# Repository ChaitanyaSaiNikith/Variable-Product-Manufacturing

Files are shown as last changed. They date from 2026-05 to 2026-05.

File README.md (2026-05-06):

# ME500 Variable Product Manufacturing — Thursday PM Lab Group

**Course:** ME500: Advanced Manufacturing — Spring 2026  
**Team:** Chris Daub, Riley Hubscher, Mukhamed Kerimkul, Bramasto Prasojo, and Chaitanya Sai Nikith Rambha  

---

## Project Overview

This project implements a **Variable Product Manufacturing (VPM)** system in the ADML. The system autonomously produces two variants of a swivel hook product — **Short Hook (Product A)** and **Tall Hook (Product B)** — each consisting of a CNC-machined lid, a CNC-machined base, and a 3D-printed hook. A computer vision system identifies the lid type and directs the correct assembly procedure.

The system integrates three UR5 robots (Rosie, Mary, Edie), two Haas Mini Mills (Cayenne, Paprika), a conveyor belt, an Allen-Bradley SLC500 PLC, and a top-down webcam — all orchestrated by BUMES (Boston University Manufacturing Execution System).

---

## Products

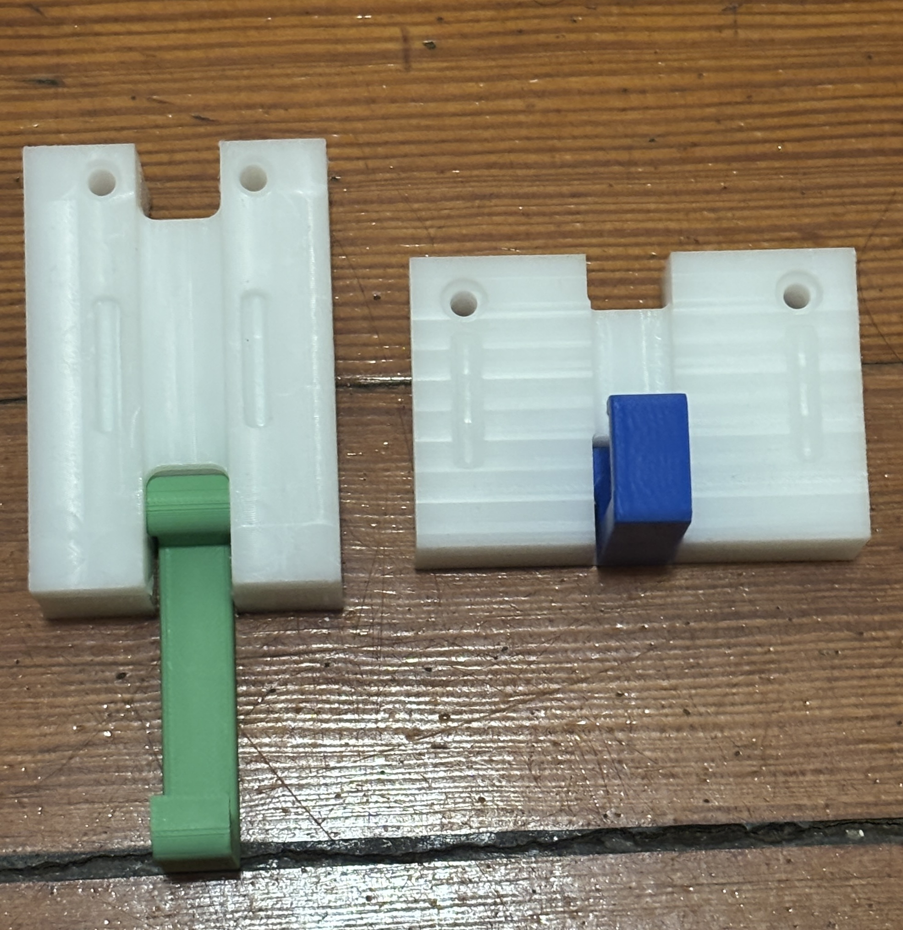
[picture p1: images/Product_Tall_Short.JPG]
Short and Tall Hook Products

*Left: Tall Hook (Product B) — Right: Short Hook (Product B)*

Each product consists of:
- A CNC-machined HDPE **lid** (Haas Mini Mill)
- A CNC-machined HDPE **base** (Haas Mini Mill)
- A 3D-printed PLA **hook** (Bambu Labs, ~20 min print time)

---

## Lab Layout

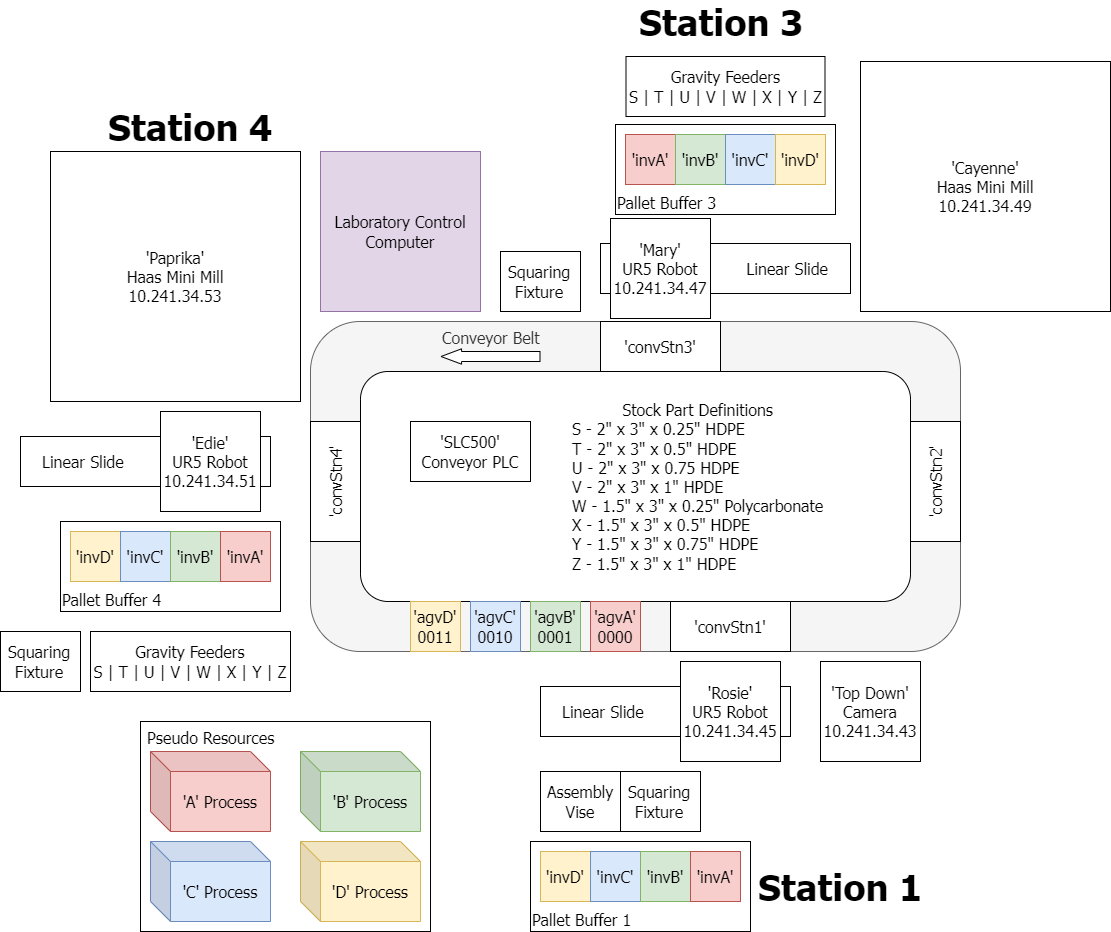
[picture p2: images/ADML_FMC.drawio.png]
ADML FMC Layout

*ADML Flexible Manufacturing Cell — Stations 1, 3, and 4*

| Station | Robot | Mill | Key Resources |
|---|---|---|---|
| Station 1 | Rosie (10.241.34.45) | — | Assembly Vise, Squaring Fixture, Top-Down Camera (10.241.34.43), Pallet Buffer 1 |
| Station 3 | Mary (10.241.34.47) | Cayenne (10.241.34.49) | Squaring Fixture, Pallet Buffer 3 |
| Station 4 | Edie (10.241.34.51) | Paprika (10.241.34.53) | Squaring Fixture, Pallet Buffer 4 |

AGVs (`agvA`–`agvD`) transport pallets between stations via the conveyor belt, controlled by the `SLC500` Conveyor PLC.

---

## Supporting Hardware

### Assembly Fixture
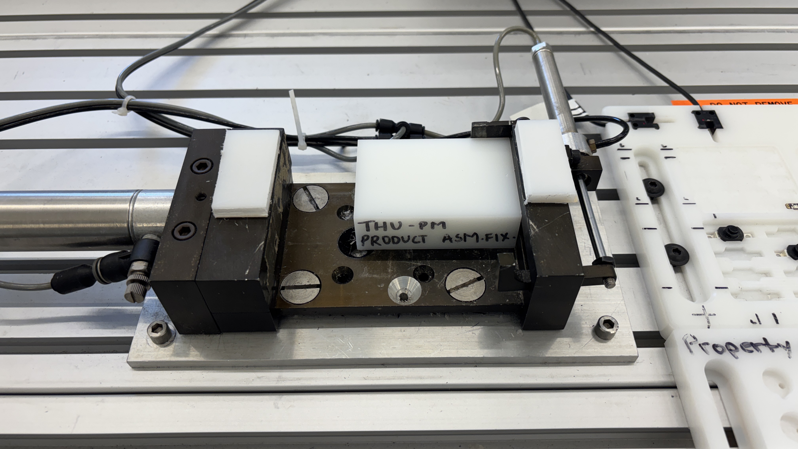
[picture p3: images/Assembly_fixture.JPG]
Assembly Fixture

*THU-PM Product Assembly Fixture at Station 1 — used by Rosie to assemble lid, base, and hook*

### Hook Tray
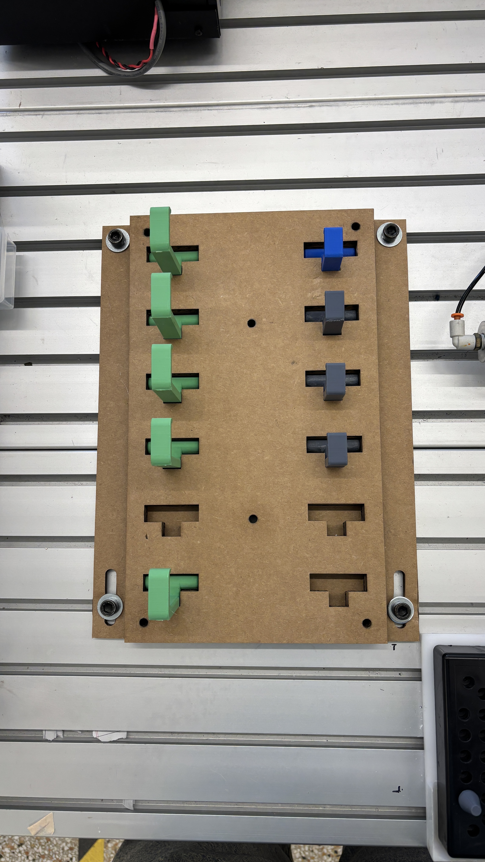
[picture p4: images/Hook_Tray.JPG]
Hook Tray

*Laser-cut cardboard hook inventory tray — holds Short (green) and Tall (blue/grey) hooks*

### Pallet Peg Locations
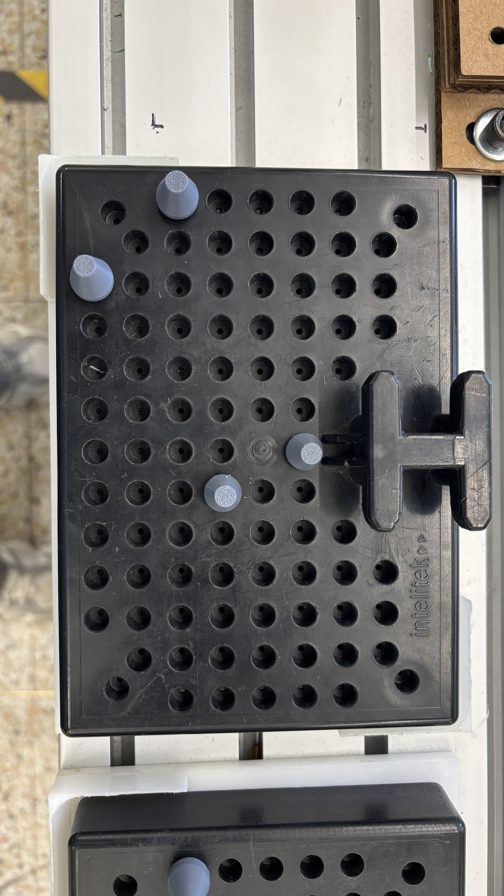
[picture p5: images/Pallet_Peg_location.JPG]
Pallet Peg Location

*3D-printed grey pegs on inventory pallet — replace reflective metal pegs that interfered with computer vision*

### Camera Scan Peg Location
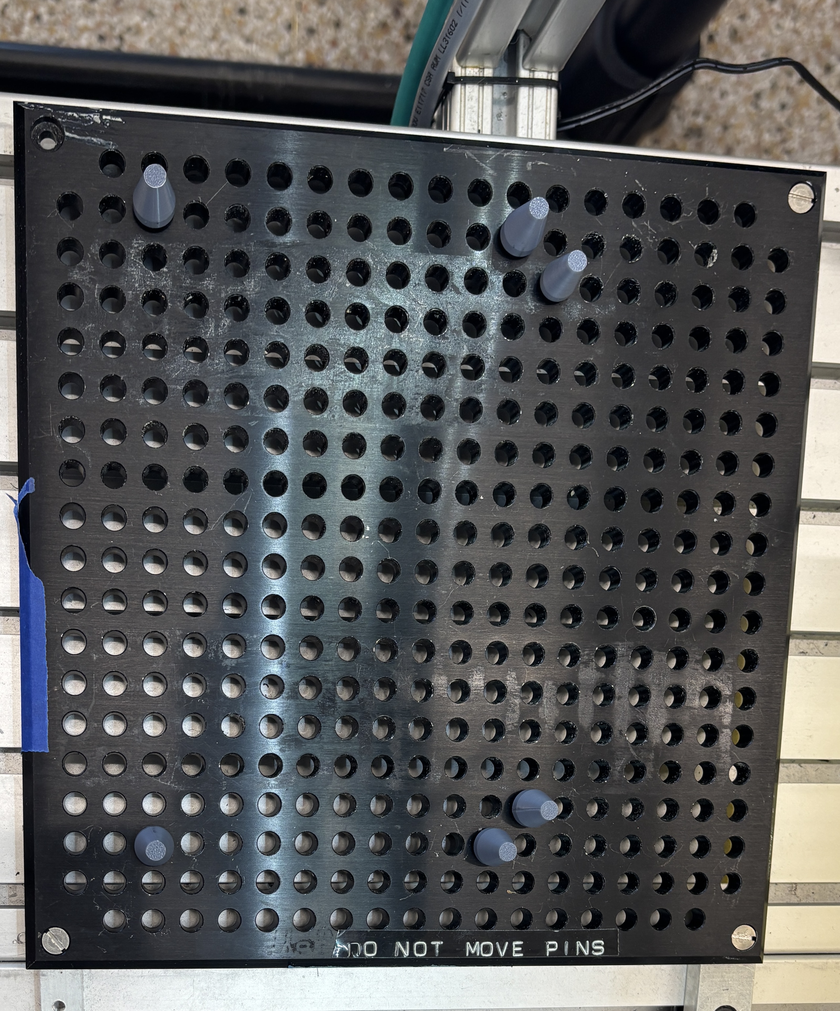
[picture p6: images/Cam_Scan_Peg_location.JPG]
Camera Scan Peg Location

*Peg configuration on the camera scan station — used during vision system lid classification*

---

## Repository Structure

```
Variable-Product-Manufacturing/
│
├── BUMES/
│   ├── Assembly.txt
│   ├── ShortLid.txt           # BUMES script: Short Lid (Stations 3→1)
│   ├── ShortBody.txt          # BUMES script: Short Body + Assembly (Stations 4→1)
│   ├── TallLid.txt            # BUMES script: Tall Lid (Stations 3→1)
│   └── TallBody.txt           # BUMES script: Tall Body + Assembly (Stations 4→1)
│
├── CAD:CAM Files/
│   ├── AssemblyA2.SLDASM      # SolidWorks assembly: Product A
│   ├── AssemblyB2.SLDASM      # SolidWorks assembly: Product B
│   ├── Assembly1.zip          # Fusion 360 CAM: Product A
│   ├── Assembly1V.zip         # Fusion 360 CAM: Product B
│   ├── AssemblyA Step/        # STEP files: Base1, Lid1, Hook1
│   ├── AssemblyB step/        # STEP files: Base1V, Lid1V, Hook1V
│   ├── Base1.SLDPRT           # SolidWorks: Short base
│   ├── Base1V.SLDPRT          # SolidWorks: Tall base
│   ├── Lid 1.SLDPRT           # SolidWorks: Short lid
│   ├── Lid1V.SLDPRT           # SolidWorks: Tall lid
│   ├── Hook1.SLDPRT           # SolidWorks: Short hook
│   ├── Hook1V.SLDPRT          # SolidWorks: Tall hook
│   ├── Base1CNC_1.png         # CAM setup screenshot: Short base
│   ├── Base1VCNC_1.png        # CAM setup screenshot: Tall base
│   ├── Lid1CNC_1.png          # CAM setup screenshot: Short lid
│   ├── Lid1VCNC_1.png         # CAM setup screenshot: Tall lid
│   ├── Hook 3d Print/
│   │   ├── Hook1.STL          # STL: Short hook
│   │   └── Hook1V.STL         # STL: Tall hook
│   └── NC Programs/
│       ├── ThPmLidA_1.nc      # G-code: Short Lid (O01021)
│       ├── ThPmBaseA_1.nc     # G-code: Short Base (O01011)
│       ├── ThPmLidB_1.nc      # G-code: Tall Lid (O02021)
│       └── ThPmBaseB_1.nc     # G-code: Tall Base (O02011)
│
├── Documentation/
│   ├── BUMES Operation Guide.docx
│   ├── CAD_CAM Documentation.docx
│   ├── Integration & Vision Scripts.docx
│   └── URP Files.docx
│
├── Rosie/                     # UR5 Robot at Station 1
│   ├── _adminCG-*.urp/script/txt     # Pallet movement admin programs
│   ├── _adminLinearIndex*.urp        # Linear slide positioning
│   ├── Assembly_Vision.urp           # Conditional assembly based on vision result
│   ├── hookA_manager.urp             # Short hook pick logic
│   ├── hookB_manager.urp             # Tall hook pick logic
│   ├── Short_LidToCamera.urp         # Move short lid to camera + run vision
│   ├── Tall_LidToCamera.urp          # Move tall lid to camera + run vision
│   └── vision_pc_modbus.script       # Triggers vision.py and writes Modbus result
│
├── Mary/                      # UR5 Robot at Station 3
│   ├── _adminCG-*.urp/script/txt     # Pallet movement admin programs
│   ├── _adminLinearIndex5.urp        # Linear slide positioning
│   ├── gravityFeederT.urp            # Collect and square Stock T
│   ├── Short_StockT_LoadMill_MakePart_Tier1.urp
│   ├── Short_Lid_UnloadMill.urp
│   ├── Short_PHomeToInvA.urp
│   ├── Tall_StockT_LoadMill_MakePart_Tier3.urp
│   ├── Tall_Lid_UnloadMill.urp
│   └── Tall_PHomeToInvC.urp
│
├── Edie/                      # UR5 Robot at Station 4
│   ├── _adminCG-*.urp/script/txt     # Pallet movement admin programs
│   ├── _adminLinearIndex2.urp        # Linear slide positioning
│   ├── gravityFeederV.urp            # Collect and square Stock V
│   ├── Short_StockV_LoadMill_MakePart_Tier1.urp
│   ├── Short_Body_UnloadMill_Tier1.urp
│   ├── Short_PHomeToInvB.urp
│   ├── Tall_StockV_LoadMill_MakePart_Tier3.urp
│   ├── Tall_Body_UnloadMill_Tier3.urp
│   └── Tall_PHomeToInvD.urp
│
├── Vision/
│   ├── listener_server.py     # TCP server: receives trigger from Rosie
│   ├── listener_server_test.py
│   ├── modbus_server.py       # Modbus server: posts vision results to Rosie
│   ├── vision.py              # Core vision algorithm (lidTypeIndicator)
│   ├── vision_utils.py        # Shared utilities and RESULT_CODES
│   ├── vision_test.py         # Bulk and individual test harness
│   └── BulkTest/
│       ├── short1.png         # Sample short lid test image
│       └── tall1.png          # Sample tall lid test image
│
├── images/
│   ├── ADML_FMC.drawio.png
│   ├── Product_Tall_Short.JPG
│   ├── Assembly_fixture.JPG
│   ├── Hook_Tray.JPG
│   ├── Pallet_Peg_location.JPG
│   └── Cam_Scan_Peg_location.JPG
│
├── ME 500 Final Video Demo .mp4
├── THU PM FINAL Project Update.pptx
└── README.md
```

---

## Vision System

The computer vision system runs on the Station 1 computer and classifies lids as **Short** or **Tall** using a webcam and OpenCV.

### Algorithm (in `vision.py`)

1. **Capture** — `scan()` connects to the webcam, buffers 30 frames, and captures an image
2. **Crop** — `clipBlacks()` thresholds near-white pixels; `findLargestConnected()` isolates the lid area; `crop()` extracts it
3. **Process** — `findHoles()` uses a blob detector (tuned for circularity, area) to locate the two through-holes; `calcHoleSpacing()` measures inter-hole distance
4. **Classify** — `lidTypeByHoles()` compares distance against threshold **85**:
   - Short lid: ~110px spacing
   - Tall lid: ~60px spacing
   - Threshold sits ~11 standard deviations from both means — effectively perfect accuracy

### Communication Flow
```
Rosie triggers lid scan
        ↓
listener_server.py (TCP port 30002, HOST=10.241.34.37)
        ↓
vision.py → lidTypeIndicator()
        ↓
modbus_server.py (port 502) writes result to register 0
        ↓
Rosie reads Modbus register → runs Assembly_Vision.urp
```

### Setup

Requires **Python 3.14.3**. Set up a virtual environment in VS Code to avoid conflicts with existing lab software.

```bash
pip install -r requirements.txt
```

Start the servers in two separate terminals **before** running BUMES:

```bash
python listener_server.py
python modbus_server.py
```

---

## BUMES Operation Guide

### Prerequisites

1. Turn on all machines: robots, CNC mills, conveyor belt, and master air supply
2. Connect the computer vision webcam to BUMES Computer 1 (Station 1)
3. Populate pallet inventory bays near Rosie with pallets set for **stock sizes T and V** using 3D-printed pegs
4. Press **"Run Program"** on each robot's touchscreen
5. Select **Program 9000** on each CNC mill; clear errors with Reset, then press "Power up/Restart"
6. Fill gravity feeders with **stocks T and V**
7. Initialize BUMES on BUMES Computer 1
8. Start the vision servers (see above)

### Running the System

Queue and run all four BUMES programs simultaneously:

| Script | Stations | Produces | Pallet | Stock |
|---|---|---|---|---|
| ShortLid | 3 → 1 | Lid A (short) + Assembly| invA / agvA | T (Tier 1) |
| ShortBody | 4 → 1 | Body A (short)  | invB / agvB | V (Tier 1) |
| TallLid | 3 → 1 | Lid B (tall) + Assembly | invC / agvC | T (Tier 3) |
| TallBody | 4 → 1 | Body B (tall)  | invD / agvD | V (Tier 3) |

Assembly is triggered by **ShortBody** and **TallBody** after the vision system confirms the lid type. Rosie performs the final assembly and delivers the product to the output box.

---

## CNC Programs

| Program | File | Machine | Stock | Tier | Part |
|---|---|---|---|---|---|
| O01021 | ThPmLidA_1.nc | Cayenne | T | 1 | Short Lid |
| O01011 | ThPmBaseA_1.nc | Paprika | V | 1 | Short Base |
| O02021 | ThPmLidB_1.nc | Cayenne | T | 3 | Tall Lid |
| O02011 | ThPmBaseB_1.nc | Paprika | V | 3 | Tall Base |

**WCS Origin:** Bottom, back, right corner of stock when facing the machine from the sliding door side.

**Tools used:** T1 ⅛" flat end mill, T2 ¼" flat end mill, T3 ⅜" flat end mill, T4 ½" flat end mill, T5 ¼" 90° spot drill, T6 3/16" drill

---

## 3D Print Settings (Hooks)

Printed on a **Bambu Labs** printer using **Bambu Studio** slicer, standard PLA, 0.2mm layer height:

| Setting | Value |
|---|---|
| Sparse Infill Density | 6% |
| Sparse Infill Pattern | Gyroid |
| Supports | Tree (auto) |

Print time: ~20 minutes per hook.

---

## Key Network Addresses

| Device | IP Address |
|---|---|
| Rosie (UR5, Station 1) | 10.241.34.45 |
| Mary (UR5, Station 3) | 10.241.34.47 |
| Edie (UR5, Station 4) | 10.241.34.51 |
| Cayenne (Haas, Station 3) | 10.241.34.49 |
| Paprika (Haas, Station 4) | 10.241.34.53 |
| Top-Down Camera | 10.241.34.43 |
| Vision Server (listener) | 10.241.34.37 : 30002 |
| Modbus Server | 0.0.0.0 : 502 |

---

## Shutdown

1. Allow all machines to complete their current cycle
2. Power off robots, CNC mills, and conveyor belt per their respective manuals
3. Return all pallets to their designated storage locations

---

## Dependencies

- Python 3.14.3
- OpenCV (`cv2`) — [opencv.org](https://opencv.org)
- pymodbus
- Full list in `Vision/requirements.txt`

---
## Video Demo Drive Link
https://drive.google.com/file/d/13W8RlCqD1YdOIOgoTWztGpp7VzRbSrjd/view?usp=sharing
## Acknowledgments

Developed as part of ME500: Advanced Manufacturing, Spring 2026, Boston University.  
Special thanks to professor Boley and to the ADML staff Adam and Caroline for lab support and infrastructure.

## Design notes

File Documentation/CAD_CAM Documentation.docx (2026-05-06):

# CAD and CAM Supporting Documentation

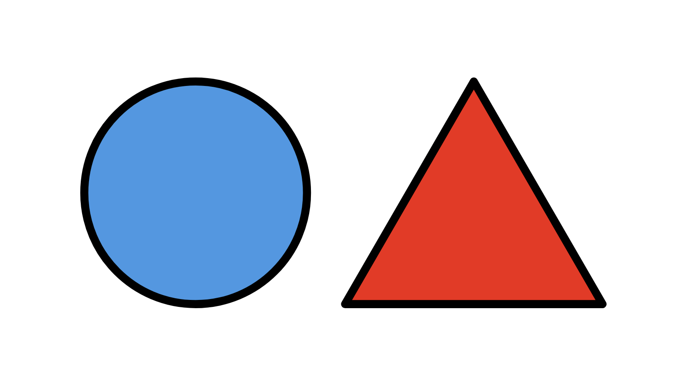
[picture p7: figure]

ME500: Advanced Manufacturing

Spring 2026

Variable Product Manufacturing (Thursday PM Lab Group)

Chris Daub, Riley Hubscher, Mukhamed Kerimkul, Bramasto Prasojo, and Chaitanya Sai Nikith Rambha

Table of Contents

Overview 3

Short Hook 3

Base1.sldprt 3

Base1CNC_1.f3z 4

Lid1.sldprt 5

Lid1CNC_1.f3z 6

Hook1.sldprt 7

Hook1.stl 8

Tall Hook 10

Base1V.sldprt 10

Base1VCNC_1.f3z 10

Lid1V.sldprt 11

Lid1VCNC_1.f3z 12

Hook1V.sldprt 13

Hook1V.stl 14

Hook Tray 16

tray.dxf 16

Inventory Pallet Pegs 16

PegSmall.stl and PegMed.stl 16

Appendix A: CAM Program Plaintext 17

Product A: Lid 17

Product A: Base 47

Product B: Lid 120

Product B: Base 150

# Overview

Each product consists of a unique matching CNC-machined lid and base made in the ADML, and a FDM-printed unique hook printed externally. The lid features a friction-fit connection to the base. Both lid and base have a through hole for a 3/16 wall screw to go through. The hook has a flat detent for the hook to remain in the closed and open position. All files have been submitted to Blackboard in a ZIP file with this document.

# Short Hook

### Base1.sldprt

The base features horizontal slot pegs, through holes, a pocket for the hook joint to rest in, and a channel for the hook end to rest in when closed. shown below:

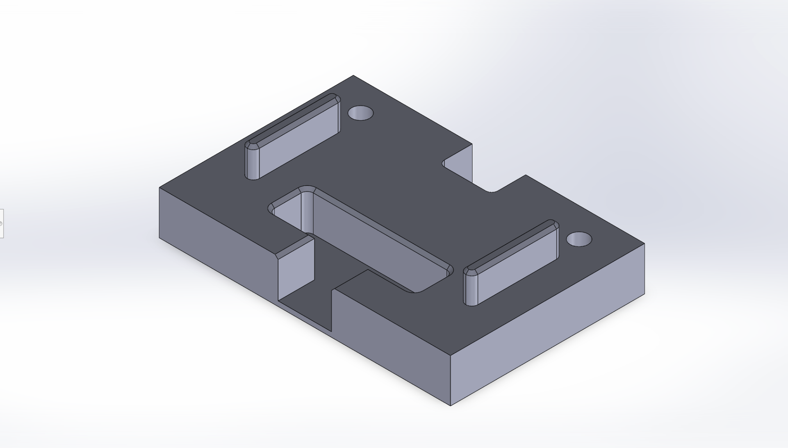
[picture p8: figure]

### Base1CNC_1.f3z

The CAM program assumes HDPE stock V is placed horizontally in Tier 1 of the vice. The program assumes the machine WCS origin is set in the bottom, back, right corner of the stock when facing into the machine from the side with the sliding door, shown below:

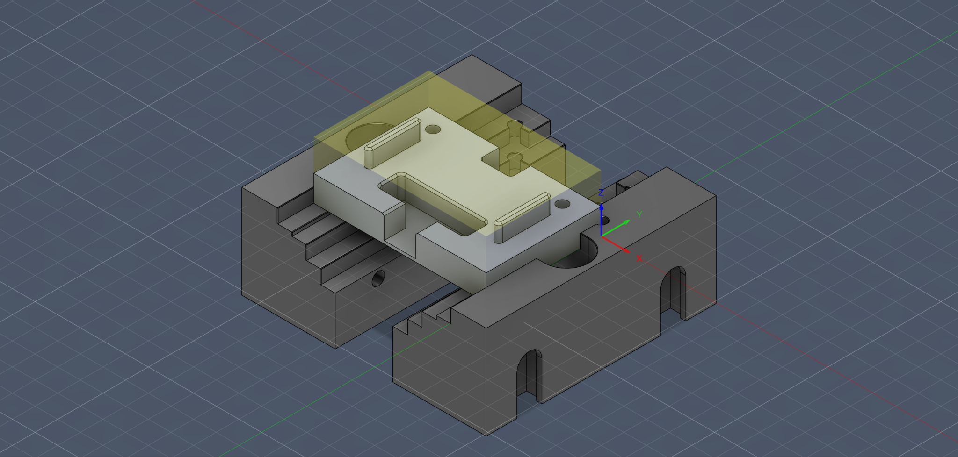
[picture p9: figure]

No special tooling outside the standard ADML tools are required. Utilized the following tools: T6 ⅜ drill, T5 ¼ 90 degree spot drill, T4 ½ flat end mill, T3 ⅜ flat end mill, and T1 ⅛ flat end mill. Primarily utilized the flat milling function in Fusion360 to mill the majority of the geometry with finishing passes with T1 for dimensional accuracy. Approximate machining time is 5-6 minutes.

### Lid1.sldprt

The lid is an H shape piece with 2 channels on the top and bottom which features horizontal slotted holes with relieve pockets, counterbored holes, and a flat pocket in the middle for the hook to rest in shown below:

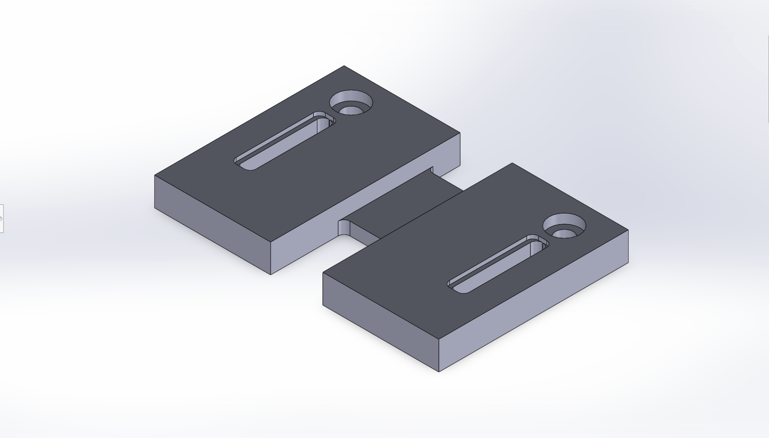
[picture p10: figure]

### Lid1CNC_1.f3z

The CAM program assumes HDPE stock T is placed horizontally in Tier 1 of the vice. The program assumes the machine WCS origin is set in the bottom, back, right corner of the stock when facing into the machine from the side with the sliding door, shown below:

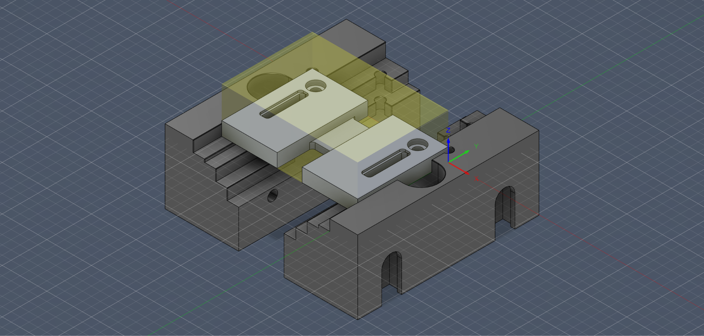
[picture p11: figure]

No special tooling outside the standard ADML tools are required. Utilized the following tools: T4 ½ flat end mill, and T1 ⅛ flat end mill. Utilized the large T4 to cut the channel and flat pockets as the final operation to reduce time the thin geometry is under clamping pressure from the vice. Approximate machining time is 5-6 minutes.

### Hook1.sldprt

Hook pivot pegs dimensions, shaft thickness, hook shape, and detent height are conformed. The height and length of this hook is the shorter of the two with the detent placed for a 90 degree open position. It is shown below:

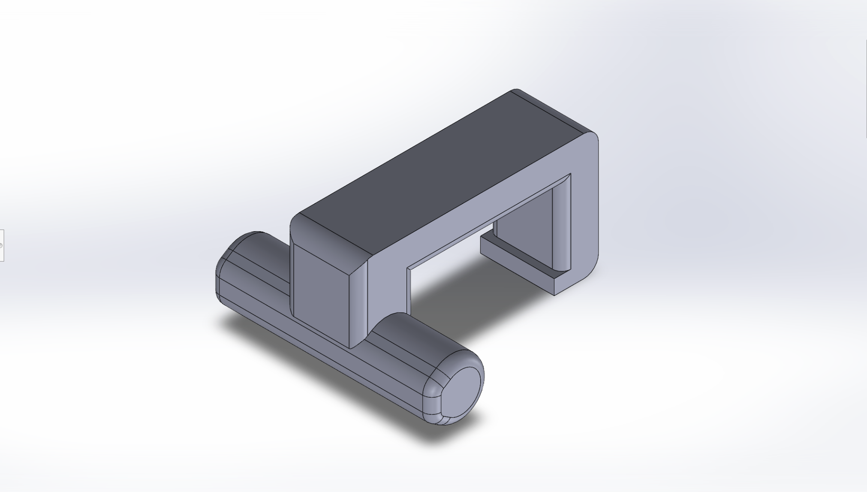
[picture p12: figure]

### Hook1.stl

The recommended printing orientation is shown below:

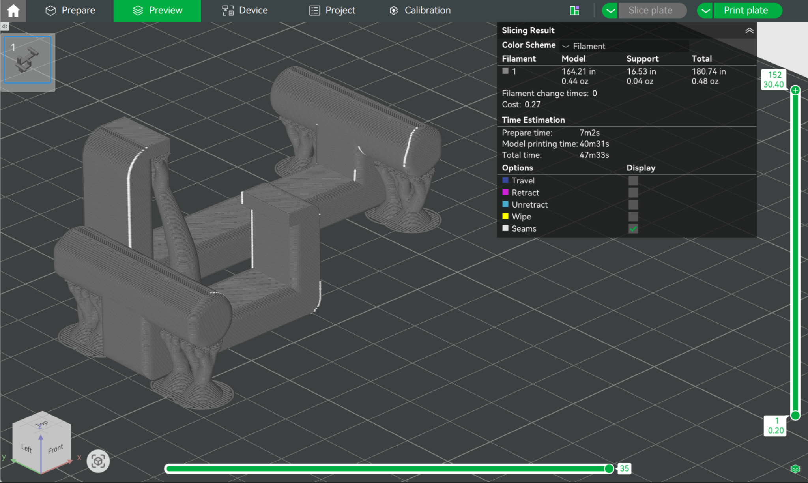
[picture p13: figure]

The hooks were printed on a Bambu Labs printer using Bambu Studio as the slicer. Standard PLA was used. The print profile used was the standard 0.2mm layer height profile, and the only settings changed from default were the following:

Setting | New value
Sparse Infill Density | 6%
Sparse Infill Pattern | Gyroid
Enable Supports | Tree (auto)

Print time is roughly 20 minutes per hook.

# Tall Hook

### Base1V.sldprt

The base features horizontal slot pegs, through holes, a pocket for the hook joint to rest in, relieve flat pocket for the lid to rest into, a channel at the south end of the part for the hook to rest while in its open state, and a channel at the north of the part for the hook end to rest in when closed. shown below:

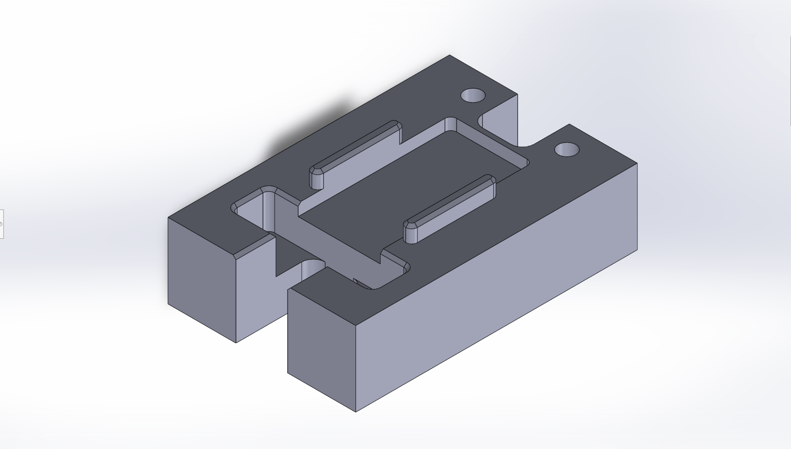
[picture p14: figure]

### Base1VCNC_1.f3z

The CAM program assumes HDPE stock V is placed vertically in Tier 2 of the vice. The program assumes the machine WCS origin is set in the bottom, back, right corner of the stock when facing into the machine from the side with the sliding door, shown below:

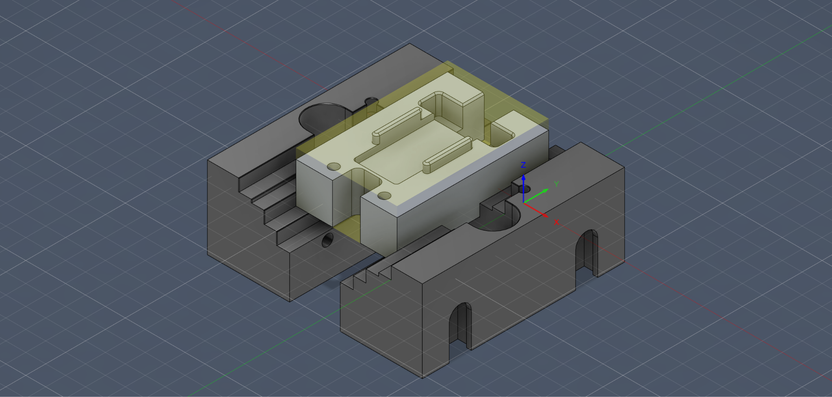
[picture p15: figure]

No special tooling outside the standard ADML tools are required. Utilized the following tools: T6 ⅜ drill, T5 ¼ 90 degree spot drill, T4 ½ flat end mill, T3 ⅜ flat end mill, T2 ¼ flat end mill, and T1 ⅛ flat end mill. Primarily utilized the pocket and horizontal milling function using T3 in Fusion360 to mill the majority of the geometry with finishing passes with T1 for dimensional accuracy. Approximate machining time is 5-6 minutes.

### Lid1V.sldprt

The base is an H shape piece with 2 channels on the top and bottom which features horizontal slotted holes with relieve pockets, chamfered holes, and a flat pocket in the middle for the hook to rest in shown below:

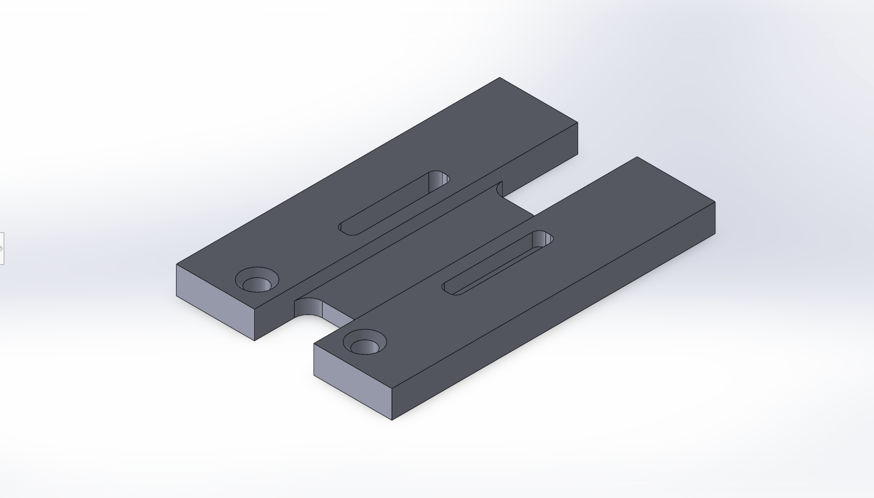
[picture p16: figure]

### Lid1VCNC_1.f3z

The CAM program assumes HDPE stock T is placed vertically in Tier 2 of the vice. The program assumes the machine WCS origin is set in the bottom, back, right corner of the stock when facing into the machine from the side with the sliding door, shown below:

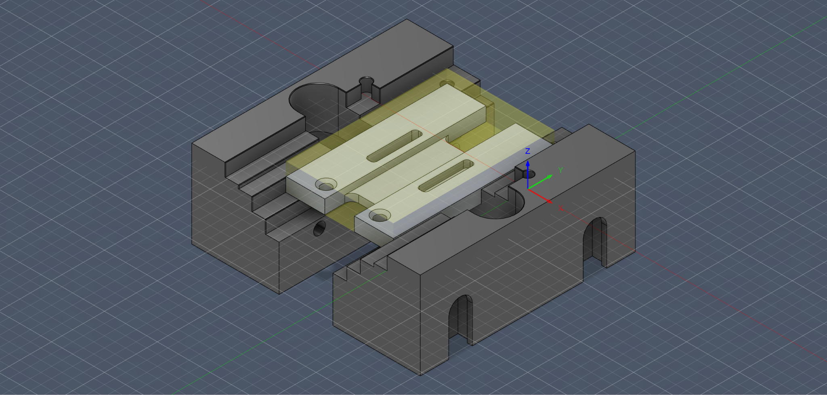
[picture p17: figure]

No special tooling outside the standard ADML tools are required. Utilized the following tools: T5 ¼ 90 degree spot drill, T4 ½ flat end mill, and T1 ⅛ flat end mill. Due to the low space below the vice a ramped lead in is used to face the part. Utilized the large T4 to cut the channel and flat pockets as the final operation to reduce time the thin geometry is under clamping pressure from the vice. Approximate machining time is 5-6 minutes.

### Hook1V.sldprt

Hook pivot pegs dimensions, shaft thickness, hook shape, and detent height are conformed. The height and length of this hook is the longer of the two with the detent placed for a 180 degree open position. It is shown below:

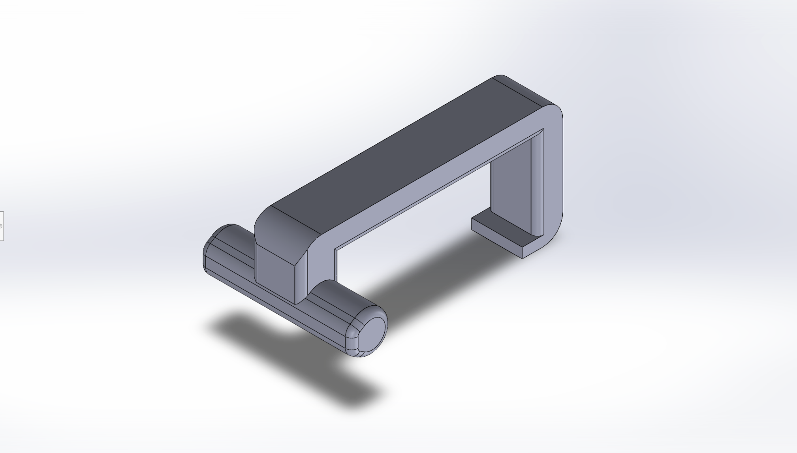
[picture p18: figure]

### Hook1V.stl

The recommended printing orientation is shown below:

The hooks were printed on a Bambu Labs printer using Bambu Studio as the slicer. Standard PLA was used. The print profile used was the standard 0.2mm layer height profile, and the only settings changed from default were the following:

Setting | New value
Sparse Infill Density | 6%
Sparse Infill Pattern | Gyroid
Enable Supports | Tree (auto)

Print time is roughly 20 minutes per hook.

# Hook Tray

### tray.dxf

The hook inventory trays are cut from laser cut layers of corrugated cardboard and formed by stacking. The files are included in the project submission.

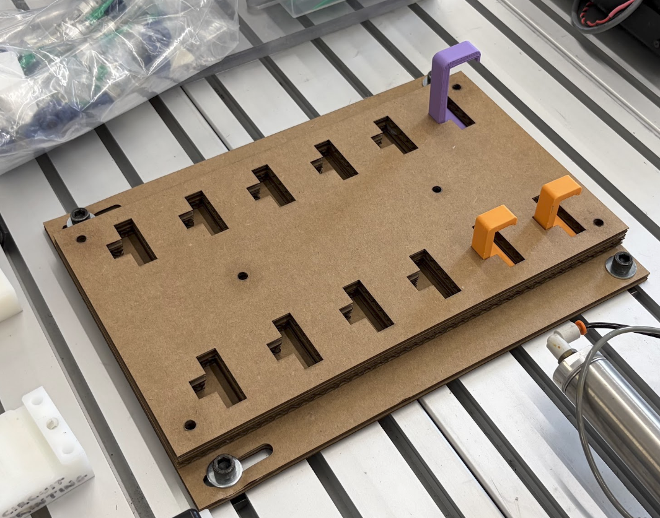
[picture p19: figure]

# Inventory Pallet Pegs

### PegSmall.stl and PegMed.stl

The aluminum inventory pallet pegs caused issues with computer vision readings due to their reflectivity, and were thus replaced with 3D printed grey examples. Their STL files are included in the submission.

# Appendix A: CAM Program Plaintext

### Product A: Lid

%

O01021 (ThPmLidA)

(Using high feed G1 F196.85 instead of G0.)

(T1 D=0.125 CR=0. - ZMIN=-0.0787 - flat end mill)

(T4 D=0.5 CR=0. - ZMIN=-0.0591 - flat end mill)

N10 G90 G17

N15 G20

N20 G53 G0 Z0.

(Face1)

N25 T4 M6

N30 S9000 M3

N35 G17 G90

N40 G54

N45 M8

N50 G1 X0.3631 Y-2.0869 F196.85

N55 G0 G43 Z1.0906 H4

N60 T1

N65 G0 Z0.6969

N70 G1 Z0.4917 F89.4

N75 G18 G3 X0.3131 Z0.4417 I-0.05 K0.

N80 G1 X0.3004

N85 X-3.3004

N90 G17 G2 Y-1.8761 I0. J0.1054

N95 G1 X0.3004

N100 G3 Y-1.6653 I0. J0.1054

N105 G1 X-3.3004

N110 G2 Y-1.4545 I0. J0.1054

N115 G1 X0.3004

N120 G3 Y-1.2437 I0. J0.1054

N125 G1 X-3.3004

N130 G2 Y-1.033 I0. J0.1054

N135 G1 X0.3004

N140 G3 Y-0.8222 I0. J0.1054

N145 G1 X-3.3004

N150 G2 Y-0.6114 I0. J0.1054

N155 G1 X0.3004

N160 G3 Y-0.4006 I0. J0.1054

N165 G1 X-3.3004

N170 G2 Y-0.1898 I0. J0.1054

N175 G1 X0.3004

N180 G18 G2 X0.3504 Z0.4917 I0. K0.05

N185 G0 Z0.6969

N190 G1 X0.3631 Y-2.0869 F196.85

N195 Z0.4228 F89.4

N200 G3 X0.3131 Z0.3728 I-0.05 K0.

N205 G1 X0.3004

N210 X-3.3004

N215 G17 G2 Y-1.8761 I0. J0.1054

N220 G1 X0.3004

N225 G3 Y-1.6653 I0. J0.1054

N230 G1 X-3.3004

N235 G2 Y-1.4545 I0. J0.1054

N240 G1 X0.3004

N245 G3 Y-1.2437 I0. J0.1054

N250 G1 X-3.3004

N255 G2 Y-1.033 I0. J0.1054

N260 G1 X0.3004

N265 G3 Y-0.8222 I0. J0.1054

N270 G1 X-3.3004

N275 G2 Y-0.6114 I0. J0.1054

N280 G1 X0.3004

N285 G3 Y-0.4006 I0. J0.1054

N290 G1 X-3.3004

N295 G2 Y-0.1898 I0. J0.1054

N300 G1 X0.3004

N305 G18 G2 X0.3504 Z0.4228 I0. K0.05

N310 G0 Z0.6969

N315 G1 X0.3631 Y-2.0869 F196.85

N320 Z0.3539 F89.4

N325 G3 X0.3131 Z0.3039 I-0.05 K0.

N330 G1 X0.3004

N335 X-3.3004

N340 G17 G2 Y-1.8761 I0. J0.1054

N345 G1 X0.3004

N350 G3 Y-1.6653 I0. J0.1054

N355 G1 X-3.3004

N360 G2 Y-1.4545 I0. J0.1054

N365 G1 X0.3004

N370 G3 Y-1.2437 I0. J0.1054

N375 G1 X-3.3004

N380 G2 Y-1.033 I0. J0.1054

N385 G1 X0.3004

N390 G3 Y-0.8222 I0. J0.1054

N395 G1 X-3.3004

N400 G2 Y-0.6114 I0. J0.1054

N405 G1 X0.3004

N410 G3 Y-0.4006 I0. J0.1054

N415 G1 X-3.3004

N420 G2 Y-0.1898 I0. J0.1054

N425 G1 X0.3004

N430 G18 G2 X0.3504 Z0.3539 I0. K0.05

N435 G0 Z1.0906

N440 M9

N445 M5

N450 G53 G0 Z0.

(2D Pocket4)

N455 M1

N460 T1 M6

N465 S6000 M3

N470 G17 G90

N475 G54

N480 M8

N485 G1 X-0.3391 Y-0.5991 F196.85

N490 G0 G43 Z1.0906 H1

N495 T4

N500 G0 Z0.5067

N505 G1 Z0.2709 F26.4

N510 X-0.3393 Z0.2684 F8.976

N515 X-0.3402 Y-0.5989 Z0.266

N520 X-0.3415 Y-0.5987 Z0.2639

N525 X-0.3432 Y-0.5985 Z0.2621

N530 X-0.3453 Y-0.5981 Z0.2607

N535 X-0.3477 Y-0.5978 Z0.2599

N540 X-0.3502 Y-0.5974 Z0.2596

N545 X-0.3799 Y-0.5927

N550 X-0.3818 Y-0.5925

N555 X-0.4181

N560 Y-1.4075

N565 X-0.3818

N570 X-0.3799 Y-1.4073

N575 X-0.3693 Y-1.4057

N580 X-0.3665 Y-1.4052 Z0.2599

N585 X-0.3639 Y-1.4048 Z0.2609

N590 X-0.3616 Y-1.4044 Z0.2624

N595 X-0.3596 Y-1.4041 Z0.2643

N600 X-0.3581 Y-1.4039 Z0.2667

N605 X-0.3572 Y-1.4038 Z0.2693

N610 X-0.3569 Y-1.4037 Z0.2721

N615 G0 Z1.0906

N620 G1 X-0.4102 Y-1.401 F196.85

N625 G0 Z0.5067

N630 G1 Z0.2709 F26.4

N635 X-0.4099 Z0.2684 F8.976

N640 X-0.4091 Y-1.4012 Z0.266

N645 X-0.4078 Y-1.4014 Z0.2639

N650 X-0.406 Y-1.4017 Z0.2621

N655 X-0.4039 Y-1.402 Z0.2607

N660 X-0.4015 Y-1.4024 Z0.2599

N665 X-0.3991 Y-1.4028 Z0.2596

N670 X-0.3701 Y-1.4073

N675 X-0.3682 Y-1.4075

N680 X-0.3319

N685 Y-0.5925

N690 X-0.3682

N695 X-0.3701 Y-0.5927

N700 X-0.3807 Y-0.5943

N705 X-0.3835 Y-0.5948 Z0.2599

N710 X-0.3861 Y-0.5952 Z0.2609

N715 X-0.3884 Y-0.5956 Z0.2624

N720 X-0.3904 Y-0.5959 Z0.2643

N725 X-0.3919 Y-0.5961 Z0.2667

N730 X-0.3928 Y-0.5962 Z0.2693

N735 X-0.3931 Y-0.5963 Z0.2721

N740 G0 Z1.0906

N745 G1 X-2.5891 Y-0.5991 F196.85

N750 G0 Z0.5067

N755 G1 Z0.2709 F26.4

N760 X-2.5893 Z0.2684 F8.976

N765 X-2.5902 Y-0.5989 Z0.266

N770 X-2.5915 Y-0.5987 Z0.2639

N775 X-2.5932 Y-0.5985 Z0.2621

N780 X-2.5953 Y-0.5981 Z0.2607

N785 X-2.5977 Y-0.5978 Z0.2599

N790 X-2.6002 Y-0.5974 Z0.2596

N795 X-2.6299 Y-0.5927

N800 X-2.6318 Y-0.5925

N805 X-2.6681

N810 Y-1.4075

N815 X-2.6318

N820 X-2.6299 Y-1.4073

N825 X-2.6193 Y-1.4057

N830 X-2.6165 Y-1.4052 Z0.2599

N835 X-2.6139 Y-1.4048 Z0.2609

N840 X-2.6116 Y-1.4044 Z0.2624

N845 X-2.6096 Y-1.4041 Z0.2643

N850 X-2.6081 Y-1.4039 Z0.2667

N855 X-2.6072 Y-1.4038 Z0.2693

N860 X-2.6069 Y-1.4037 Z0.2721

N865 G0 Z1.0906

N870 G1 X-2.6602 Y-1.401 F196.85

N875 G0 Z0.5067

N880 G1 Z0.2709 F26.4

N885 X-2.6599 Z0.2684 F8.976

N890 X-2.6591 Y-1.4012 Z0.266

N895 X-2.6578 Y-1.4014 Z0.2639

N900 X-2.656 Y-1.4017 Z0.2621

N905 X-2.6539 Y-1.402 Z0.2607

N910 X-2.6515 Y-1.4024 Z0.2599

N915 X-2.6491 Y-1.4028 Z0.2596

N920 X-2.6201 Y-1.4073

N925 X-2.6182 Y-1.4075

N930 X-2.5819

N935 Y-0.5925

N940 X-2.6182

N945 X-2.6201 Y-0.5927

N950 X-2.6307 Y-0.5943

N955 X-2.6335 Y-0.5948 Z0.2599

N960 X-2.6361 Y-0.5952 Z0.2609

N965 X-2.6384 Y-0.5956 Z0.2624

N970 X-2.6404 Y-0.5959 Z0.2643

N975 X-2.6419 Y-0.5961 Z0.2667

N980 X-2.6428 Y-0.5962 Z0.2693

N985 X-2.6431 Y-0.5963 Z0.2721

N990 G0 Z1.0906

(2D Pocket4 2)

N995 G1 X-0.3713 Y-0.6799 F196.85

N1000 G0 Z1.0906

N1005 Z0.5067

N1010 G1 Z0.4208 F26.4

N1015 G19 G3 Y-0.6678 Z0.4083 J0.0125 K0.

N1020 G1 Y-0.5925 Z0.4056

N1025 X-0.3787 Z0.4054

N1030 X-0.3788 Y-1.4075 Z0.3769

N1035 X-0.3713 Z0.3767

N1040 Y-0.5925 Z0.3482

N1045 X-0.3787 Z0.3479

N1050 X-0.3788 Y-1.4075 Z0.3195

N1055 X-0.3713 Z0.3192

N1060 Y-0.5925 Z0.2907

N1065 X-0.3787 Z0.2905

N1070 X-0.3788 Y-1.4075 Z0.262

N1075 X-0.3713 Z0.2618

N1080 Y-0.5925 Z0.2333

N1085 X-0.3787 Z0.233

N1090 X-0.3788 Y-1.4075 Z0.2046

N1095 X-0.3713 Z0.2043

N1100 Y-0.5925 Z0.1759

N1105 X-0.3787 Z0.1756

N1110 X-0.3788 Y-1.4075 Z0.1471

N1115 X-0.3713 Z0.1469

N1120 Y-0.5925 Z0.1184

N1125 X-0.3787 Z0.1182

N1130 X-0.3788 Y-1.4075 Z0.0897

N1135 X-0.3713 Z0.0894

N1140 Y-0.5925 Z0.061

N1145 X-0.3787 Z0.0607

N1150 X-0.3788 Y-1.4075 Z0.0322

N1155 X-0.3713 Z0.032

N1160 Y-0.5925 Z0.0035

N1165 X-0.3787 Z0.0033

N1170 X-0.3788 Y-1.4075 Z-0.0252

N1175 X-0.3713 Z-0.0255

N1180 Y-1.4038 Z-0.0256

N1185 Y-0.5925 F8.976

N1190 X-0.3787

N1195 X-0.3788 Y-1.4075

N1200 X-0.3713

N1205 Y-1.4038

N1210 X-0.3714 Y-1.4026 Z-0.0254

N1215 X-0.3717 Y-1.4015 Z-0.0251

N1220 X-0.3721 Y-1.4006 Z-0.0245

N1225 X-0.3727 Y-1.3998 Z-0.0238

N1230 X-0.3737 Y-1.3989 Z-0.0218

N1235 X-0.374 Y-1.3986 Z-0.0195

N1240 G0 Z0.6969

N1245 G1 X-2.6288 Y-1.3201 F196.85

N1250 G0 Z0.5067

N1255 G1 Z0.4208 F26.4

N1260 G2 Y-1.3322 Z0.4083 J-0.0125 K0.

N1265 G1 Y-1.4075 Z0.4056

N1270 X-2.6213 Z0.4054

N1275 Y-0.5925 Z0.3769

N1280 X-2.6288 Z0.3767

N1285 Y-1.4075 Z0.3482

N1290 X-2.6213 Z0.3479

N1295 Y-0.5925 Z0.3195

N1300 X-2.6288 Z0.3192

N1305 Y-1.4075 Z0.2907

N1310 X-2.6213 Z0.2905

N1315 Y-0.5925 Z0.262

N1320 X-2.6288 Z0.2618

N1325 Y-1.4075 Z0.2333

N1330 X-2.6213 Z0.233

N1335 Y-0.5925 Z0.2046

N1340 X-2.6288 Z0.2043

N1345 Y-1.4075 Z0.1759

N1350 X-2.6213 Z0.1756

N1355 Y-0.5925 Z0.1471

N1360 X-2.6288 Z0.1469

N1365 Y-1.4075 Z0.1184

N1370 X-2.6213 Z0.1182

N1375 Y-0.5925 Z0.0897

N1380 X-2.6288 Z0.0894

N1385 Y-1.4075 Z0.061

N1390 X-2.6213 Z0.0607

N1395 Y-0.5925 Z0.0322

N1400 X-2.6288 Z0.032

N1405 Y-1.4075 Z0.0035

N1410 X-2.6213 Z0.0033

N1415 Y-0.5925 Z-0.0252

N1420 X-2.6288 Z-0.0255

N1425 Y-0.5962 Z-0.0256

N1430 Y-1.4075 F8.976

N1435 X-2.6213

N1440 Y-0.5925

N1445 X-2.6288

N1450 Y-0.5962

N1455 X-2.6286 Y-0.5974 Z-0.0254

N1460 X-2.6283 Y-0.5985 Z-0.0251

N1465 X-2.6279 Y-0.5994 Z-0.0245

N1470 X-2.6273 Y-0.6002 Z-0.0238

N1475 X-2.6263 Y-0.6011 Z-0.0218

N1480 X-2.626 Y-0.6014 Z-0.0195

N1485 G0 Z1.0906

(Bore2)

N1490 G17

N1495 G1 X-0.3867 Y-0.2929 F196.85

N1500 G0 Z1.0906

N1505 Z0.3787

N1510 G1 Z0.3125 F8.976

N1515 G19 G2 Y-0.3054 Z0.3 J-0.0125 K0.

N1520 G1 Y-0.3117

N1525 G17 G3 X-0.375 Y-0.3234 I0.0117 J0.

N1530 X-0.377 Y-0.3233 Z0.2941 I0. J0.0234

N1535 X-0.3791 Y-0.323 Z0.2882 I0.002 J0.0233

N1540 X-0.3811 Y-0.3226 Z0.2823 I0.0041 J0.023

N1545 X-0.383 Y-0.322 Z0.2763 I0.0061 J0.0226

N1550 X-0.3849 Y-0.3212 Z0.2704 I0.008 J0.022

N1555 X-0.3867 Y-0.3202 Z0.2645 I0.0099 J0.0212

N1560 X-0.3884 Y-0.3191 Z0.2586 I0.0117 J0.0202

N1565 X-0.39 Y-0.3179 Z0.2527 I0.0134 J0.0191

N1570 X-0.3915 Y-0.3165 Z0.2468 I0.015 J0.0179

N1575 X-0.3929 Y-0.315 Z0.2409 I0.0165 J0.0165

N1580 X-0.3941 Y-0.3134 Z0.2349 I0.0179 J0.015

N1585 X-0.3952 Y-0.3117 Z0.229 I0.0191 J0.0134

N1590 X-0.3962 Y-0.3099 Z0.2231 I0.0202 J0.0117

N1595 X-0.397 Y-0.308 Z0.2172 I0.0212 J0.0099

N1600 X-0.3976 Y-0.3061 Z0.2113 I0.022 J0.008

N1605 X-0.398 Y-0.3041 Z0.2054 I0.0226 J0.0061

N1610 X-0.3983 Y-0.302 Z0.1995 I0.023 J0.0041

N1615 X-0.3984 Y-0.3 Z0.1935 I0.0233 J0.002

N1620 X-0.3983 Y-0.298 Z0.1876 I0.0234 J0.

N1625 X-0.398 Y-0.2959 Z0.1817 I0.0233 J-0.002

N1630 X-0.3976 Y-0.2939 Z0.1758 I0.023 J-0.0041

N1635 X-0.397 Y-0.292 Z0.1699 I0.0226 J-0.0061

N1640 X-0.3962 Y-0.2901 Z0.164 I0.022 J-0.008

N1645 X-0.3952 Y-0.2883 Z0.1581 I0.0212 J-0.0099

N1650 X-0.3941 Y-0.2866 Z0.1521 I0.0202 J-0.0117

N1655 X-0.3929 Y-0.285 Z0.1462 I0.0191 J-0.0134

N1660 X-0.3915 Y-0.2835 Z0.1403 I0.0179 J-0.015

N1665 X-0.39 Y-0.2821 Z0.1344 I0.0165 J-0.0165

N1670 X-0.3884 Y-0.2809 Z0.1285 I0.015 J-0.0179

N1675 X-0.3867 Y-0.2798 Z0.1226 I0.0134 J-0.0191

N1680 X-0.3849 Y-0.2788 Z0.1167 I0.0117 J-0.0202

N1685 X-0.383 Y-0.278 Z0.1107 I0.0099 J-0.0212

N1690 X-0.3811 Y-0.2774 Z0.1048 I0.008 J-0.022

N1695 X-0.3791 Y-0.277 Z0.0989 I0.0061 J-0.0226

N1700 X-0.377 Y-0.2767 Z0.093 I0.0041 J-0.023

N1705 X-0.375 Y-0.2766 Z0.0871 I0.002 J-0.0233

N1710 X-0.373 Y-0.2767 Z0.0812 I0. J-0.0234

N1715 X-0.3709 Y-0.277 Z0.0753 I-0.002 J-0.0233

N1720 X-0.3689 Y-0.2774 Z0.0693 I-0.0041 J-0.023

N1725 X-0.367 Y-0.278 Z0.0634 I-0.0061 J-0.0226

N1730 X-0.3651 Y-0.2788 Z0.0575 I-0.008 J-0.022

N1735 X-0.3633 Y-0.2798 Z0.0516 I-0.0099 J-0.0212

N1740 X-0.3616 Y-0.2809 Z0.0457 I-0.0117 J-0.0202

N1745 X-0.36 Y-0.2821 Z0.0398 I-0.0134 J-0.0191

N1750 X-0.3585 Y-0.2835 Z0.0339 I-0.015 J-0.0179

N1755 X-0.3571 Y-0.285 Z0.0279 I-0.0165 J-0.0165

N1760 X-0.3559 Y-0.2866 Z0.022 I-0.0179 J-0.015

N1765 X-0.3548 Y-0.2883 Z0.0161 I-0.0191 J-0.0134

N1770 X-0.3538 Y-0.2901 Z0.0102 I-0.0202 J-0.0117

N1775 X-0.353 Y-0.292 Z0.0043 I-0.0212 J-0.0099

N1780 X-0.3524 Y-0.2939 Z-0.0016 I-0.022 J-0.008

N1785 X-0.352 Y-0.2959 Z-0.0075 I-0.0226 J-0.0061

N1790 X-0.3517 Y-0.298 Z-0.0135 I-0.023 J-0.0041

N1795 X-0.3516 Y-0.3 Z-0.0194 I-0.0233 J-0.002

N1800 X-0.3517 Y-0.302 Z-0.0253 I-0.0234 J0.

N1805 X-0.3833 Y-0.3219 Z-0.0295 I-0.0233 J0.002

N1810 X-0.3667 Y-0.2781 I0.0083 J0.0219

N1815 X-0.3833 Y-0.3219 I-0.0083 J-0.0219

N1820 X-0.3682 Y-0.3151 I0.0042 J0.0109

N1825 G1 X-0.366 Y-0.3092

N1830 X-0.365 Y-0.3066 Z-0.0292

N1835 X-0.3641 Y-0.3042 Z-0.0283

N1840 X-0.3632 Y-0.3019 Z-0.0268

N1845 X-0.3625 Y-0.3001 Z-0.0248

N1850 X-0.362 Y-0.2987 Z-0.0225

N1855 X-0.3617 Y-0.2978 Z-0.0198

N1860 X-0.3616 Y-0.2975 Z-0.017

N1865 G0 Z0.6969

N1870 G1 X-2.6367 Y-0.2929 F196.85

N1875 G0 Z0.3787

N1880 G1 Z0.3125 F8.976

N1885 G19 G2 Y-0.3054 Z0.3 J-0.0125 K0.

N1890 G1 Y-0.3117

N1895 G17 G3 X-2.625 Y-0.3234 I0.0117 J0.

N1900 X-2.627 Y-0.3233 Z0.2941 I0. J0.0234

N1905 X-2.6291 Y-0.323 Z0.2882 I0.002 J0.0233

N1910 X-2.6311 Y-0.3226 Z0.2823 I0.0041 J0.023

N1915 X-2.633 Y-0.322 Z0.2763 I0.0061 J0.0226

N1920 X-2.6349 Y-0.3212 Z0.2704 I0.008 J0.022

N1925 X-2.6367 Y-0.3202 Z0.2645 I0.0099 J0.0212

N1930 X-2.6384 Y-0.3191 Z0.2586 I0.0117 J0.0202

N1935 X-2.64 Y-0.3179 Z0.2527 I0.0134 J0.0191

N1940 X-2.6415 Y-0.3165 Z0.2468 I0.015 J0.0179

N1945 X-2.6429 Y-0.315 Z0.2409 I0.0165 J0.0165

N1950 X-2.6441 Y-0.3134 Z0.2349 I0.0179 J0.015

N1955 X-2.6452 Y-0.3117 Z0.229 I0.0191 J0.0134

N1960 X-2.6462 Y-0.3099 Z0.2231 I0.0202 J0.0117

N1965 X-2.647 Y-0.308 Z0.2172 I0.0212 J0.0099

N1970 X-2.6476 Y-0.3061 Z0.2113 I0.022 J0.008

N1975 X-2.648 Y-0.3041 Z0.2054 I0.0226 J0.0061

N1980 X-2.6483 Y-0.302 Z0.1995 I0.023 J0.0041

N1985 X-2.6484 Y-0.3 Z0.1935 I0.0233 J0.002

N1990 X-2.6483 Y-0.298 Z0.1876 I0.0234 J0.

N1995 X-2.648 Y-0.2959 Z0.1817 I0.0233 J-0.002

N2000 X-2.6476 Y-0.2939 Z0.1758 I0.023 J-0.0041

N2005 X-2.647 Y-0.292 Z0.1699 I0.0226 J-0.0061

N2010 X-2.6462 Y-0.2901 Z0.164 I0.022 J-0.008

N2015 X-2.6452 Y-0.2883 Z0.1581 I0.0212 J-0.0099

N2020 X-2.6441 Y-0.2866 Z0.1521 I0.0202 J-0.0117

N2025 X-2.6429 Y-0.285 Z0.1462 I0.0191 J-0.0134

N2030 X-2.6415 Y-0.2835 Z0.1403 I0.0179 J-0.015

N2035 X-2.64 Y-0.2821 Z0.1344 I0.0165 J-0.0165

N2040 X-2.6384 Y-0.2809 Z0.1285 I0.015 J-0.0179

N2045 X-2.6367 Y-0.2798 Z0.1226 I0.0134 J-0.0191

N2050 X-2.6349 Y-0.2788 Z0.1167 I0.0117 J-0.0202

N2055 X-2.633 Y-0.278 Z0.1107 I0.0099 J-0.0212

N2060 X-2.6311 Y-0.2774 Z0.1048 I0.008 J-0.022

N2065 X-2.6291 Y-0.277 Z0.0989 I0.0061 J-0.0226

N2070 X-2.627 Y-0.2767 Z0.093 I0.0041 J-0.023

N2075 X-2.625 Y-0.2766 Z0.0871 I0.002 J-0.0233

N2080 X-2.623 Y-0.2767 Z0.0812 I0. J-0.0234

N2085 X-2.6209 Y-0.277 Z0.0753 I-0.002 J-0.0233

N2090 X-2.6189 Y-0.2774 Z0.0693 I-0.0041 J-0.023

N2095 X-2.617 Y-0.278 Z0.0634 I-0.0061 J-0.0226

N2100 X-2.6151 Y-0.2788 Z0.0575 I-0.008 J-0.022

N2105 X-2.6133 Y-0.2798 Z0.0516 I-0.0099 J-0.0212

N2110 X-2.6116 Y-0.2809 Z0.0457 I-0.0117 J-0.0202

N2115 X-2.61 Y-0.2821 Z0.0398 I-0.0134 J-0.0191

N2120 X-2.6085 Y-0.2835 Z0.0339 I-0.015 J-0.0179

N2125 X-2.6071 Y-0.285 Z0.0279 I-0.0165 J-0.0165

N2130 X-2.6059 Y-0.2866 Z0.022 I-0.0179 J-0.015

N2135 X-2.6048 Y-0.2883 Z0.0161 I-0.0191 J-0.0134

N2140 X-2.6038 Y-0.2901 Z0.0102 I-0.0202 J-0.0117

N2145 X-2.603 Y-0.292 Z0.0043 I-0.0212 J-0.0099

N2150 X-2.6024 Y-0.2939 Z-0.0016 I-0.022 J-0.008

N2155 X-2.602 Y-0.2959 Z-0.0075 I-0.0226 J-0.0061

N2160 X-2.6017 Y-0.298 Z-0.0135 I-0.023 J-0.0041

N2165 X-2.6016 Y-0.3 Z-0.0194 I-0.0233 J-0.002

N2170 X-2.6017 Y-0.302 Z-0.0253 I-0.0234 J0.

N2175 X-2.6333 Y-0.3219 Z-0.0295 I-0.0233 J0.002

N2180 X-2.6167 Y-0.2781 I0.0083 J0.0219

N2185 X-2.6333 Y-0.3219 I-0.0083 J-0.0219

N2190 X-2.6182 Y-0.3151 I0.0042 J0.0109

N2195 G1 X-2.616 Y-0.3092

N2200 X-2.615 Y-0.3066 Z-0.0292

N2205 X-2.6141 Y-0.3042 Z-0.0283

N2210 X-2.6132 Y-0.3019 Z-0.0268

N2215 X-2.6125 Y-0.3001 Z-0.0248

N2220 X-2.612 Y-0.2987 Z-0.0225

N2225 X-2.6117 Y-0.2978 Z-0.0198

N2230 X-2.6116 Y-0.2975 Z-0.017

N2235 G0 Z1.0906

(2D Contour4)

N2240 G1 X-0.3125 Y-0.3125 F196.85

N2245 G0 Z1.0906

N2250 Z0.6969

N2255 G1 Z0.525 F26.4

N2260 Z0.2125

N2265 G18 G2 X-0.3 Z0.2 I0.0125 K0.

N2270 G1 X-0.2875

N2275 G17 G3 X-0.275 Y-0.3 I0. J0.0125

N2280 X-0.475 I-0.1 J0.

N2285 X-0.275 I0.1 J0.

N2290 X-0.2875 Y-0.2875 I-0.0125 J0.

N2295 G1 X-0.3

N2300 G18 G3 X-0.3125 Z0.2125 I0. K0.0125

N2305 G0 Z0.6969

N2310 G1 X-2.5614 Y-0.3037 F196.85

N2315 Z0.525 F26.4

N2320 Z0.2125

N2325 X-2.5611 Y-0.3036 Z0.2097

N2330 X-2.5601 Y-0.3035 Z0.2071

N2335 X-2.5587 Y-0.3033 Z0.2047

N2340 X-2.5567 Y-0.303 Z0.2027

N2345 X-2.5544 Y-0.3027 Z0.2012

N2350 X-2.5517 Y-0.3023 Z0.2003

N2355 X-2.549 Y-0.3019 Z0.2

N2360 X-2.5366 Y-0.3002

N2365 G17 G3 X-2.526 Y-0.2861 I-0.0017 J0.0124

N2370 X-2.724 Y-0.3139 I-0.099 J-0.0139

N2375 X-2.526 Y-0.2861 I0.099 J0.0139

N2380 X-2.5401 Y-0.2754 I-0.0124 J-0.0017

N2385 G1 X-2.5525 Y-0.2772

N2390 X-2.5552 Y-0.2776 Z0.2003

N2395 X-2.5578 Y-0.2779 Z0.2012

N2400 X-2.5602 Y-0.2783 Z0.2027

N2405 X-2.5621 Y-0.2785 Z0.2047

N2410 X-2.5636 Y-0.2788 Z0.2071

N2415 X-2.5645 Y-0.2789 Z0.2097

N2420 X-2.5648 Z0.2125

N2425 G0 Z1.0906

(2D Contour3 2)

N2430 G1 X-2.6313 Y-0.3125 F196.85

N2435 G0 Z1.0906

N2440 Z0.6969

N2445 G1 Z0.525 F26.4

N2450 Z-0.017

N2455 G18 G2 X-2.6188 Z-0.0295 I0.0125 K0. F8.976

N2460 G1 X-2.6063

N2465 G17 G3 X-2.5938 Y-0.3 I0. J0.0125

N2470 X-2.625 Y-0.2688 I-0.0312 J0.

N2475 Y-0.3312 I0. J-0.0312

N2480 X-2.5938 Y-0.3 I0. J0.0312

N2485 X-2.6063 Y-0.2875 I-0.0125 J0.

N2490 G1 X-2.6188

N2495 G18 G3 X-2.6313 Z-0.017 I0. K0.0125

N2500 G0 Z0.6969

N2505 G1 X-0.3813 Y-0.3125 F196.85

N2510 Z0.525 F26.4

N2515 Z-0.017

N2520 G2 X-0.3688 Z-0.0295 I0.0125 K0. F8.976

N2525 G1 X-0.3563

N2530 G17 G3 X-0.3438 Y-0.3 I0. J0.0125

N2535 X-0.375 Y-0.2688 I-0.0312 J0.

N2540 Y-0.3312 I0. J-0.0312

N2545 X-0.3438 Y-0.3 I0. J0.0312

N2550 X-0.3563 Y-0.2875 I-0.0125 J0.

N2555 G1 X-0.3688

N2560 G18 G3 X-0.3813 Z-0.017 I0. K0.0125

N2565 G0 Z1.0906

(2D Contour10)

N2570 G17

N2575 G1 X-1.325 Y-1.3 F196.85

N2580 G0 Z1.0906

N2585 Z0.6969

N2590 G1 Z0.525 F26.4

N2595 Z0.1475

N2600 G18 G2 X-1.3125 Z0.135 I0.0125 K0.

N2605 G1 X-1.3

N2610 G17 G3 X-1.2875 Y-1.2875 I0. J0.0125

N2615 G1 Y-0.2875

N2620 G3 X-1.3 Y-0.275 I-0.0125 J0.

N2625 G1 X-1.3125

N2630 G18 G3 X-1.325 Z0.1475 I0. K0.0125

N2635 G0 Z0.6969

N2640 X-1.675

N2645 G1 Z0.525 F26.4

N2650 Z0.1475

N2655 G3 X-1.6875 Z0.135 I-0.0125 K0.

N2660 G1 X-1.7

N2665 G17 G3 X-1.7125 Y-0.2875 I0. J-0.0125

N2670 G1 Y-1.2875

N2675 G3 X-1.7 Y-1.3 I0.0125 J0.

N2680 G1 X-1.6875

N2685 G18 G2 X-1.675 Z0.1475 I0. K0.0125

N2690 G0 Z1.0906

N2695 M9

N2700 M5

N2705 G53 G0 Z0.

(2D Pocket2)

N2710 M1

N2715 T4 M6

N2720 S8000 M3

N2725 G17 G90

N2730 G54

N2735 M8

N2740 G1 X-1.5173 Y-0.0518 F196.85

N2745 G0 G43 Z1.0906 H4

N2750 T1

N2755 G0 Z0.6969

N2760 G1 Z0.18 F89.4

N2765 X-1.5174 Y-0.0521 Z0.175

N2770 X-1.5175 Y-0.0529 Z0.17

N2775 X-1.5177 Y-0.0543 Z0.1651

N2780 X-1.518 Y-0.0562 Z0.1605

N2785 X-1.5184 Y-0.0586 Z0.1561

N2790 X-1.5189 Y-0.0615 Z0.1519

N2795 X-1.5194 Y-0.0648 Z0.1482

N2800 X-1.52 Y-0.0685 Z0.1448

N2805 X-1.5206 Y-0.0726 Z0.1419

N2810 X-1.5213 Y-0.077 Z0.1395

N2815 X-1.522 Y-0.0816 Z0.1375

N2820 X-1.5228 Y-0.0864 Z0.1361

N2825 X-1.5236 Y-0.0913 Z0.1353

N2830 X-1.5244 Y-0.0962 Z0.135

N2835 Y-0.0965

N2840 X-1.5249 Y-0.1003

N2845 X-1.525 Y-0.104

N2850 Y-1.4705

N2855 G3 X-1.5168 Y-1.4788 I0.0083 J0.

N2860 G1 X-1.4918 Y-1.4791

N2865 G3 X-1.4915 Y-1.4624 I0.0001 J0.0083

N2870 X-1.4919 Y-1.4791 I-0.0002 J-0.0083

N2875 G1 X-1.4836 Y-1.4794

N2880 G3 X-1.475 Y-1.471 I0.0003 J0.0083

N2885 G1 Y-0.1045

N2890 X-1.4752 Y-0.1006

N2895 X-1.4756 Y-0.0967

N2900 X-1.4759 Y-0.0948

N2905 X-1.4768 Y-0.0892 Z0.1353

N2910 X-1.4777 Y-0.0838 Z0.1363

N2915 X-1.4785 Y-0.0785 Z0.1378

N2920 X-1.4793 Y-0.0733 Z0.14

N2925 X-1.4801 Y-0.0685 Z0.1427

N2930 X-1.4808 Y-0.064 Z0.1459

N2935 X-1.4815 Y-0.0598 Z0.1496

N2940 X-1.482 Y-0.0562 Z0.1538

N2945 X-1.4825 Y-0.0529 Z0.1584

N2950 X-1.483 Y-0.0503 Z0.1633

N2955 X-1.4833 Y-0.0482 Z0.1685

N2960 X-1.4835 Y-0.0466 Z0.1739

N2965 X-1.4837 Y-0.0457 Z0.1794

N2970 Y-0.0454 Z0.185

N2975 G0 Z1.0906

(2D Contour1)

N2980 G1 X-1.3701 Y0.2097 F196.85

N2985 G0 Z1.0906

N2990 Z0.6969

N2995 G1 Z0.5394 F89.4

N3000 Z-0.0091

N3005 G18 G3 X-1.4201 Z-0.0591 I-0.05 K0.

N3010 G1 X-1.4701

N3015 G17 G3 X-1.5201 Y0.1597 I0. J-0.05

N3020 G1 Y0.

N3025 Y-0.0951

N3030 X-1.4799

N3035 Y0.1823

N3040 G3 X-1.5299 Y0.2323 I-0.05 J0.

N3045 G1 X-1.5799

N3050 G18 G3 X-1.6299 Z-0.0091 I0. K0.05

N3055 G0 Z0.6969

N3060 Y-2.2097

N3065 G1 Z0.5394 F89.4

N3070 Z-0.0091

N3075 G2 X-1.5799 Z-0.0591 I0.05 K0.

N3080 G1 X-1.5299

N3085 G17 G3 X-1.4799 Y-2.1597 I0. J0.05

N3090 G1 Y-1.4799

N3095 X-1.5201

N3100 Y-2.

N3105 Y-2.1823

N3110 G3 X-1.4701 Y-2.2323 I0.05 J0.

N3115 G1 X-1.4201

N3120 G18 G2 X-1.3701 Z-0.0091 I0. K0.05

N3125 G0 Z1.0906

N3130 M9

N3135 M5

N3140 G53 G0 Z0.

(2D Contour3)

N3145 M1

N3150 T1 M6

N3155 S6000 M3

N3160 G17 G90

N3165 G54

N3170 M8

N3175 G1 X-1.5625 Y0.05 F196.85

N3180 G0 G43 Z1.0906 H1

N3185 T4

N3190 G0 Z0.6969

N3195 G1 Z0.525 F26.4

N3200 Z-0.0287

N3205 G18 G3 X-1.6125 Z-0.0787 I-0.05 K0.

N3210 G1 X-1.6625

N3215 G17 G3 X-1.7125 Y0. I0. J-0.05

N3220 G1 Y-0.2875

N3225 X-1.2875

N3230 Y0.

N3235 G3 X-1.3375 Y0.05 I-0.05 J0.

N3240 G1 X-1.3875

N3245 G18 G3 X-1.4375 Z-0.0287 I0. K0.05

N3250 G0 Z0.6969

N3255 Y-2.05

N3260 G1 Z0.525 F26.4

N3265 Z-0.0287

N3270 G2 X-1.3875 Z-0.0787 I0.05 K0.

N3275 G1 X-1.3375

N3280 G17 G3 X-1.2875 Y-2. I0. J0.05

N3285 G1 Y-1.2875

N3290 X-1.7125

N3295 Y-2.

N3300 G3 X-1.6625 Y-2.05 I0.05 J0.

N3305 G1 X-1.6125

N3310 G18 G2 X-1.5625 Z-0.0287 I0. K0.05

N3315 G0 Z1.0906

N3320 M5

N3325 M9

N3330 G53 G0 Z0.

N3335 X-1.5

N3340 G53 G0 Y0.

N3345 M98 P9004

N3350 M30

%

### Product A: Base

%

O01011 (ThPmBaseA)

(Using high feed G1 F500. instead of G0.)

(T1 D=0.125 CR=0. - ZMIN=-0.0394 - flat end mill)

(T3 D=0.375 CR=0. - ZMIN=0. - flat end mill)

(T4 D=0.5 CR=0. - ZMIN=0.75 - flat end mill)

(T5 D=0.25 CR=0. TAPER=90deg - ZMIN=0.3794 - spot drill)

(T6 D=0.1875 CR=0. TAPER=118deg - ZMIN=-0.0603 - drill)

N10 G90 G17

N15 G20

N20 G53 G0 Z0.

(Face2 2)

N25 T4 M6

N30 S7000 M3

N35 G17 G90

N40 G54

N45 M8

N50 G1 X0.325 Y-1.9123 F500.

N55 G0 G43 Z1.5906 H4

N60 T3

N65 G0 Z1.1969

N70 G1 Z0.8 F89.4

N75 G18 G3 X0.275 Z0.75 I-0.05 K0.

N80 G1 X0.2504

N85 X-3.2504

N90 G17 G2 Y-1.578 I0. J0.1671

N95 G1 X0.2504

N100 G3 Y-1.2437 I0. J0.1671

N105 G1 X-3.2504

N110 G2 Y-0.9095 I0. J0.1671

N115 G1 X0.2504

N120 G3 Y-0.5753 I0. J0.1671

N125 G1 X-3.2504

N130 G2 Y-0.241 I0. J0.1671

N135 G1 X0.2504

N140 G18 G2 X0.3004 Z0.8 I0. K0.05

N145 G0 Z1.5906

N150 M9

N155 M5

N160 G53 G0 Z0.

(Flat2 2)

N165 M1

N170 T3 M6

N175 S8500 M3

N180 G17 G90

N185 G54

N190 M8

N195 G1 X-1.4249 Y-2.2636 F500.

N200 G0 G43 Z1.5906 H3

N205 T1

N210 G0 Z0.833

N215 G1 Z0.5593 F67.2

N220 X-1.4248 Z0.5561

N225 X-1.4244 Y-2.2633 Z0.5516

N230 X-1.424 Y-2.2625 Z0.5471

N235 X-1.4236 Y-2.2612 Z0.5428

N240 X-1.4233 Y-2.2593 Z0.5387

N245 X-1.423 Y-2.2569 Z0.5348

N250 X-1.4227 Y-2.2542 Z0.5313

N255 X-1.4224 Y-2.251 Z0.5281

N260 X-1.4222 Y-2.2474 Z0.5253

N265 X-1.422 Y-2.2435 Z0.523

N270 X-1.4218 Y-2.2394 Z0.5211

N275 X-1.4217 Y-2.2351 Z0.5198

N280 X-1.4216 Y-2.2306 Z0.519

N285 Y-2.2261 Z0.5187

N290 X-1.4217 Y-2.1886

N295 X-1.4224 Y-1.9746

N300 Y-1.6396

N305 X-1.4217 Y-1.6091

N310 X-1.4199 Y-1.5939

N315 X-1.4168 Y-1.5787

N320 X-1.4125 Y-1.5634

N325 X-1.4068 Y-1.5482

N330 X-1.4008 Y-1.5353

N335 X-1.3913 Y-1.5187

N340 X-1.3797 Y-1.5025

N345 X-1.3664 Y-1.4873

N350 X-1.3632 Y-1.4841

N355 X-1.3479 Y-1.4706

N360 X-1.3327 Y-1.4596

N365 X-1.3153 Y-1.4495

N370 X-1.3023 Y-1.4434

N375 X-1.2871 Y-1.4377

N380 X-1.2719 Y-1.4333

N385 X-1.2567 Y-1.4302

N390 X-1.2415 Y-1.4283

N395 X-1.2111 Y-1.4276

N400 X-1.0224

N405 X-0.9474 F16.8

N410 Y-1.4223

N415 X-1.9777 F67.2

N420 X-2.0527 F16.8

N425 X-2.0526 Y-1.4276

N430 X-1.7889 F67.2

N435 X-1.7585 Y-1.4283

N440 X-1.7433 Y-1.4302

N445 X-1.7281 Y-1.4333

N450 X-1.7129 Y-1.4377

N455 X-1.6977 Y-1.4434

N460 X-1.6847 Y-1.4495

N465 X-1.6673 Y-1.4596

N470 X-1.6521 Y-1.4706

N475 X-1.6368 Y-1.4841

N480 X-1.6336 Y-1.4873

N485 X-1.6202 Y-1.5025

N490 X-1.6093 Y-1.5178

N495 X-1.5992 Y-1.5353

N500 X-1.5932 Y-1.5482

N505 X-1.5875 Y-1.5634

N510 X-1.5832 Y-1.5787

N515 X-1.5801 Y-1.5939

N520 X-1.5783 Y-1.6091

N525 X-1.5776 Y-1.6396

N530 X-1.5777 Y-2.0051

N535 X-1.5787 Y-2.0203

N540 X-1.5809 Y-2.0355

N545 X-1.5843 Y-2.0507

N550 X-1.589 Y-2.066

N555 X-1.5951 Y-2.0812

N560 X-1.6413 Y-2.1886

N565 X-1.6561 Y-2.223

N570 X-1.6578 Y-2.2272 Z0.519

N575 X-1.6595 Y-2.2313 Z0.5198

N580 X-1.6611 Y-2.2353 Z0.5211

N585 X-1.6626 Y-2.2392 Z0.523

N590 X-1.664 Y-2.2428 Z0.5253

N595 X-1.6651 Y-2.2462 Z0.5281

N600 X-1.6662 Y-2.2493 Z0.5313

N605 X-1.667 Y-2.2519 Z0.5348

N610 X-1.6676 Y-2.2542 Z0.5387

N615 X-1.668 Y-2.2561 Z0.5428

N620 X-1.6682 Y-2.2575 Z0.5471

N625 X-1.6681 Y-2.2584 Z0.5516

N630 X-1.6679 Y-2.2588 Z0.5561

N635 X-1.6678 Z0.5593

N640 G0 Z0.9799

N645 G1 X-1.7143 Y-2.1878 F500.

N650 G0 Z0.5581

N655 G1 Z0.2844 F67.2

N660 X-1.7061 Y-2.1879

N665 X-1.6979 Y-2.1886

N670 X-1.5014 Y-2.2054

N675 X-1.5

N680 X-1.4986

N685 X-1.3021 Y-2.1886

N690 X-1.2939 Y-2.1879

N695 X-1.2857 Y-2.1878

N700 X-1.3023 Y-2.1816

N705 X-1.3175 Y-2.1743

N710 X-1.3327 Y-2.1653

N715 X-1.3441 Y-2.1573

N720 X-1.3536 Y-2.1497

N725 X-1.3632 Y-2.1409

N730 X-1.3762 Y-2.1269

N735 X-1.3856 Y-2.1148

N740 X-1.3936 Y-2.1026

N745 X-1.3972 Y-2.0964

N750 X-1.4049 Y-2.0812

N755 X-1.411 Y-2.066

N760 X-1.4157 Y-2.0507

N765 X-1.4191 Y-2.0355

N770 X-1.4213 Y-2.0203

N775 X-1.4223 Y-2.0051

N780 X-1.4224 Y-1.6396

N785 X-1.4217 Y-1.6091

N790 X-1.4199 Y-1.5939

N795 X-1.4168 Y-1.5787

N800 X-1.4125 Y-1.5634

N805 X-1.4068 Y-1.5482

N810 X-1.4008 Y-1.5353

N815 X-1.3907 Y-1.5178

N820 X-1.3797 Y-1.5025

N825 X-1.3664 Y-1.4873

N830 X-1.3632 Y-1.4841

N835 X-1.3479 Y-1.4706

N840 X-1.3327 Y-1.4596

N845 X-1.3153 Y-1.4495

N850 X-1.3023 Y-1.4434

N855 X-1.2871 Y-1.4377

N860 X-1.2719 Y-1.4333

N865 X-1.2567 Y-1.4302

N870 X-1.2415 Y-1.4283

N875 X-1.2111 Y-1.4276

N880 X-1.0224

N885 X-0.9474 F16.8

N890 Y-1.4223

N895 X-1.9777 F67.2

N900 X-2.0527 F16.8

N905 X-2.0526 Y-1.4276

N910 X-1.7889 F67.2

N915 X-1.7585 Y-1.4283

N920 X-1.7433 Y-1.4302

N925 X-1.7281 Y-1.4333

N930 X-1.7129 Y-1.4377

N935 X-1.6977 Y-1.4434

N940 X-1.6847 Y-1.4495

N945 X-1.6673 Y-1.4596

N950 X-1.6521 Y-1.4706

N955 X-1.6368 Y-1.4841

N960 X-1.6336 Y-1.4873

N965 X-1.6202 Y-1.5025

N970 X-1.6093 Y-1.5178

N975 X-1.5992 Y-1.5353

N980 X-1.5932 Y-1.5482

N985 X-1.5875 Y-1.5634

N990 X-1.5832 Y-1.5787

N995 X-1.5801 Y-1.5939

N1000 X-1.5783 Y-1.6091

N1005 X-1.5776 Y-1.6396

N1010 X-1.5777 Y-2.0051

N1015 X-1.5787 Y-2.0203

N1020 X-1.5809 Y-2.0355

N1025 X-1.5843 Y-2.0507

N1030 X-1.589 Y-2.066

N1035 X-1.5951 Y-2.0812

N1040 X-1.6028 Y-2.0964

N1045 X-1.6064 Y-2.1026

N1050 X-1.6144 Y-2.1148

N1055 X-1.6238 Y-2.1269

N1060 X-1.6368 Y-2.1409

N1065 X-1.6464 Y-2.1497

N1070 X-1.6559 Y-2.1573

N1075 X-1.6673 Y-2.1653

N1080 X-1.6825 Y-2.1743

N1085 X-1.6977 Y-2.1816

N1090 X-1.7143 Y-2.1878

N1095 Z0.05

N1100 X-1.7061 Y-2.1879

N1105 X-1.6979 Y-2.1886

N1110 X-1.5014 Y-2.2054

N1115 X-1.5

N1120 X-1.4986

N1125 X-1.3021 Y-2.1886

N1130 X-1.2939 Y-2.1879

N1135 X-1.2857 Y-2.1878

N1140 X-1.3023 Y-2.1816

N1145 X-1.3175 Y-2.1743

N1150 X-1.3327 Y-2.1653

N1155 X-1.3441 Y-2.1573

N1160 X-1.3536 Y-2.1497

N1165 X-1.3632 Y-2.1409

N1170 X-1.3762 Y-2.1269

N1175 X-1.3856 Y-2.1148

N1180 X-1.3936 Y-2.1026

N1185 X-1.3972 Y-2.0964

N1190 X-1.4049 Y-2.0812

N1195 X-1.411 Y-2.066

N1200 X-1.4157 Y-2.0507

N1205 X-1.4191 Y-2.0355

N1210 X-1.4213 Y-2.0203

N1215 X-1.4223 Y-2.0051

N1220 X-1.4224 Y-1.6396

N1225 X-1.4217 Y-1.6091

N1230 X-1.4199 Y-1.5939

N1235 X-1.4168 Y-1.5787

N1240 X-1.4125 Y-1.5634

N1245 X-1.4068 Y-1.5482

N1250 X-1.4008 Y-1.5353

N1255 X-1.3907 Y-1.5178

N1260 X-1.3797 Y-1.5025

N1265 X-1.3664 Y-1.4873

N1270 X-1.3632 Y-1.4841

N1275 X-1.3479 Y-1.4706

N1280 X-1.3327 Y-1.4596

N1285 X-1.3153 Y-1.4495

N1290 X-1.3023 Y-1.4434

N1295 X-1.2871 Y-1.4377

N1300 X-1.2719 Y-1.4333

N1305 X-1.2567 Y-1.4302

N1310 X-1.2415 Y-1.4283

N1315 X-1.2111 Y-1.4276

N1320 X-1.0224

N1325 X-0.9474 F16.8

N1330 Y-1.4223

N1335 X-1.9777 F67.2

N1340 X-2.0527 F16.8

N1345 X-2.0526 Y-1.4276

N1350 X-1.7889 F67.2

N1355 X-1.7585 Y-1.4283

N1360 X-1.7433 Y-1.4302

N1365 X-1.7281 Y-1.4333

N1370 X-1.7129 Y-1.4377

N1375 X-1.6977 Y-1.4434

N1380 X-1.6847 Y-1.4495

N1385 X-1.6673 Y-1.4596

N1390 X-1.6521 Y-1.4706

N1395 X-1.6368 Y-1.4841

N1400 X-1.6336 Y-1.4873

N1405 X-1.6202 Y-1.5025

N1410 X-1.6093 Y-1.5178

N1415 X-1.5992 Y-1.5353

N1420 X-1.5932 Y-1.5482

N1425 X-1.5875 Y-1.5634

N1430 X-1.5832 Y-1.5787

N1435 X-1.5801 Y-1.5939

N1440 X-1.5783 Y-1.6091

N1445 X-1.5776 Y-1.6396

N1450 X-1.5777 Y-2.0051

N1455 X-1.5787 Y-2.0203

N1460 X-1.5809 Y-2.0355

N1465 X-1.5843 Y-2.0507

N1470 X-1.589 Y-2.066

N1475 X-1.5951 Y-2.0812

N1480 X-1.6028 Y-2.0964

N1485 X-1.6064 Y-2.1026

N1490 X-1.6144 Y-2.1148

N1495 X-1.6238 Y-2.1269

N1500 X-1.6368 Y-2.1409

N1505 X-1.6464 Y-2.1497

N1510 X-1.6559 Y-2.1573

N1515 X-1.6673 Y-2.1653

N1520 X-1.6825 Y-2.1743

N1525 X-1.6977 Y-2.1816

N1530 X-1.7143 Y-2.1878

N1535 X-1.7494 Y-2.2009

N1540 X-1.7537 Y-2.2025 Z0.0503

N1545 X-1.7578 Y-2.2041 Z0.0511

N1550 X-1.7618 Y-2.2057 Z0.0524

N1555 X-1.7656 Y-2.2073 Z0.0543

N1560 X-1.7692 Y-2.2089 Z0.0566

N1565 X-1.7725 Y-2.2103 Z0.0594

N1570 X-1.7754 Y-2.2117 Z0.0626

N1575 X-1.7779 Y-2.213 Z0.0661

N1580 X-1.7799 Y-2.2141 Z0.07

N1585 X-1.7816 Y-2.2151 Z0.0741

N1590 X-1.7827 Y-2.2159 Z0.0784

N1595 X-1.7833 Y-2.2166 Z0.0829

N1600 X-1.7834 Y-2.217 Z0.0874

N1605 Y-2.2172 Z0.0906

N1610 G0 Z1.1969

N1615 G1 X-1.2456 Y-2.2526 F500.

N1620 G0 Z0.9987

N1625 G1 Z0.725 F67.2

N1630 X-1.2455 Y-2.2525 Z0.7217

N1635 X-1.2453 Y-2.2521 Z0.7172

N1640 X-1.2454 Y-2.2512 Z0.7128

N1645 X-1.2458 Y-2.2498 Z0.7085

N1650 X-1.2465 Y-2.2481 Z0.7043

N1655 X-1.2474 Y-2.2459 Z0.7005

N1660 X-1.2486 Y-2.2433 Z0.6969

N1665 X-1.2501 Y-2.2405 Z0.6937

N1670 X-1.2518 Y-2.2373 Z0.691

N1675 X-1.2536 Y-2.2339 Z0.6886

N1680 X-1.2557 Y-2.2303 Z0.6868

N1685 X-1.2579 Y-2.2266 Z0.6854

N1690 X-1.2602 Y-2.2228 Z0.6846

N1695 X-1.2625 Y-2.2189 Z0.6844

N1700 X-1.2824 Y-2.1871

N1705 X-1.4114 Y-1.9799

N1710 X-1.4439 Y-1.9246

N1715 G3 X-1.5542 I-0.0552 J-0.0325

N1720 G1 X-1.6035 Y-2.0074

N1725 X-1.7161 Y-2.1871

N1730 X-1.736 Y-2.2189

N1735 X-1.7383 Y-2.2227 Z0.6846

N1740 X-1.7406 Y-2.2265 Z0.6854

N1745 X-1.7428 Y-2.2303 Z0.6868

N1750 X-1.7449 Y-2.2339 Z0.6886

N1755 X-1.7468 Y-2.2373 Z0.691

N1760 X-1.7485 Y-2.2404 Z0.6937

N1765 X-1.7499 Y-2.2433 Z0.6969

N1770 X-1.7511 Y-2.2458 Z0.7005

N1775 X-1.7521 Y-2.248 Z0.7043

N1780 X-1.7528 Y-2.2497 Z0.7085

N1785 X-1.7532 Y-2.2511 Z0.7128

N1790 X-1.7533 Y-2.252 Z0.7172

N1795 X-1.7531 Y-2.2524 Z0.7217

N1800 X-1.753 Y-2.2525 Z0.725

N1805 G0 Z1.1969

N1810 G1 X-1.7555 Y0.254 F500.

N1815 G0 Z0.9987

N1820 G1 Z0.725 F67.2

N1825 X-1.7556 Y0.2539 Z0.7217

N1830 X-1.7558 Y0.2535 Z0.7172

N1835 X-1.7557 Y0.2526 Z0.7128

N1840 X-1.7553 Y0.2512 Z0.7085

N1845 X-1.7546 Y0.2495 Z0.7043

N1850 X-1.7536 Y0.2473 Z0.7005

N1855 X-1.7524 Y0.2448 Z0.6969

N1860 X-1.751 Y0.2419 Z0.6937

N1865 X-1.7493 Y0.2388 Z0.691

N1870 X-1.7474 Y0.2354 Z0.6886

N1875 X-1.7453 Y0.2318 Z0.6868

N1880 X-1.7431 Y0.228 Z0.6854

N1885 X-1.7408 Y0.2242 Z0.6846

N1890 X-1.7385 Y0.2204 Z0.6844

N1895 X-1.7186 Y0.1886

N1900 X-1.5891 Y-0.0187

N1905 X-1.5565 Y-0.0739

N1910 G3 X-1.4461 I0.0552 J0.0326

N1915 G1 X-1.3966 Y0.009

N1920 X-1.284 Y0.1886

N1925 X-1.264 Y0.2203

N1930 X-1.2616 Y0.2242 Z0.6846

N1935 X-1.2593 Y0.228 Z0.6854

N1940 X-1.2571 Y0.2317 Z0.6868

N1945 X-1.2551 Y0.2353 Z0.6886

N1950 X-1.2532 Y0.2387 Z0.691

N1955 X-1.2515 Y0.2418 Z0.6937

N1960 X-1.25 Y0.2447 Z0.6969

N1965 X-1.2488 Y0.2472 Z0.7005

N1970 X-1.2479 Y0.2494 Z0.7043

N1975 X-1.2472 Y0.2512 Z0.7085

N1980 X-1.2468 Y0.2525 Z0.7128

N1985 X-1.2467 Y0.2534 Z0.7172

N1990 X-1.2469 Y0.2538 Z0.7217

N1995 X-1.247 Y0.2539 Z0.725

N2000 G0 Z1.1969

N2005 G1 X-0.9123 Y-2.2458 F500.

N2010 G0 Z0.9987

N2015 G1 Z0.725 F67.2

N2020 X-0.9122 Y-2.2457 Z0.7217

N2025 X-0.9121 Y-2.2452 Z0.7172

N2030 X-0.9124 Y-2.2444 Z0.7128

N2035 X-0.913 Y-2.2431 Z0.7085

N2040 X-0.914 Y-2.2415 Z0.7043

N2045 X-0.9154 Y-2.2396 Z0.7005

N2050 X-0.917 Y-2.2373 Z0.6969

N2055 X-0.919 Y-2.2348 Z0.6937

N2060 X-0.9213 Y-2.232 Z0.691

N2065 X-0.9238 Y-2.229 Z0.6886

N2070 X-0.9264 Y-2.2259 Z0.6868

N2075 X-0.9293 Y-2.2227 Z0.6854

N2080 X-0.9323 Y-2.2193 Z0.6846

N2085 X-0.9354 Y-2.216 Z0.6844

N2090 X-0.9609 Y-2.1886

N2095 X-1.0972 Y-2.0423

N2100 G2 X-1.3618 Y-1.3741 I0.7217 J0.6722

N2105 G1 X-1.3648 Y-0.6342

N2110 G2 X-1.1002 Y0.0422 I0.9866 J0.004

N2115 G1 X-0.9639 Y0.1886

N2120 X-0.9383 Y0.216

N2125 X-0.9353 Y0.2194 Z0.6846

N2130 X-0.9323 Y0.2227 Z0.6854

N2135 X-0.9294 Y0.2259 Z0.6868

N2140 X-0.9267 Y0.229 Z0.6886

N2145 X-0.9242 Y0.232 Z0.691

N2150 X-0.922 Y0.2348 Z0.6937

N2155 X-0.92 Y0.2373 Z0.6969

N2160 X-0.9183 Y0.2396 Z0.7005

N2165 X-0.917 Y0.2415 Z0.7043

N2170 X-0.916 Y0.2431 Z0.7085

N2175 X-0.9153 Y0.2444 Z0.7128

N2180 X-0.9151 Y0.2452 Z0.7172

N2185 X-0.9152 Y0.2457 Z0.7217

N2190 X-0.9153 Y0.2458 Z0.725

N2195 G0 Z1.1969

N2200 G1 X0.2525 Y-1.8643 F500.

N2205 G0 Z0.9987

N2210 G1 Z0.725 F67.2

N2215 X0.2524 Y-1.8642 Z0.7217

N2220 X0.2519 Y-1.864 Z0.7172

N2225 X0.251 Y-1.8641 Z0.7128

N2230 X0.2497 Y-1.8646 Z0.7085

N2235 X0.248 Y-1.8653 Z0.7043

N2240 X0.2458 Y-1.8664 Z0.7005

N2245 X0.2434 Y-1.8677 Z0.6969

N2250 X0.2406 Y-1.8693 Z0.6937

N2255 X0.2375 Y-1.8711 Z0.691

N2260 X0.2342 Y-1.8731 Z0.6886

N2265 X0.2307 Y-1.8753 Z0.6868

N2270 X0.227 Y-1.8776 Z0.6854

N2275 X0.2233 Y-1.8801 Z0.6846

N2280 X0.2196 Y-1.8826 Z0.6844

N2285 X0.1886 Y-1.9037

N2290 X0.0536 Y-1.9958

N2295 G2 X-0.3698 Y-2.1273 I-0.4261 J0.6245

N2300 G1 X-0.3716

N2305 G2 X-0.9068 Y-1.908 I-0.0027 J0.7561

N2310 G1 X-0.9081 Y-1.9067

N2315 G2 X-1.1316 Y-1.3731 I0.5326 J0.5367

N2320 G1 X-1.1346 Y-0.6332

N2325 G2 X-0.9151 Y-0.0974 I0.7564 J0.0031

N2330 G1 X-0.9138 Y-0.0961

N2335 G2 X-0.3796 Y0.1275 I0.5369 J-0.5328

N2340 G1 X-0.3779

N2345 G2 X0.054 Y-0.006 I0.0027 J-0.7564

N2350 G1 X0.1886 Y-0.0988

N2355 G3 X0.2025 Y-0.0812 I0.0064 J0.0092

N2360 G1 X-0.0215 Y0.1222

N2365 G3 X-0.0971 Y0.0745 I-0.0312 J-0.0343

N2370 G2 X-0.0653 Y-0.1039 I-0.7503 J-0.2257

N2375 G3 X0.0067 Y-0.2702 I0.2654 J0.0161

N2380 G2 X0.1499 Y-0.6294 I-0.3827 J-0.3608

N2385 G1 X0.1522 Y-1.3675

N2390 G2 X-0.899 Y-1.3713 I-0.5256 J-0.0016

N2395 G1 X-0.902 Y-0.6332

N2400 G2 X0.0067 Y-0.2702 I0.526 J0.0021

N2405 X-0.0107 Y-0.5097 I-0.1185 J-0.1117

N2410 G3 X-0.1152 Y-0.7258 I0.1713 J-0.2161

N2415 G1 Y-1.4112

N2420 X-0.1163 Y-1.4288

N2425 X-0.1179 Y-1.4428

N2430 X-0.1207 Y-1.4575

N2435 X-0.1239 Y-1.4721

N2440 X-0.1286 Y-1.4873

N2445 X-0.1342 Y-1.5025

N2450 X-0.1409 Y-1.5178

N2455 X-0.1467 Y-1.5288

N2460 X-0.1582 Y-1.5482

N2465 X-0.1771 Y-1.5734

N2470 X-0.1817 Y-1.5787

N2475 X-0.1946 Y-1.5919

N2480 X-0.2075 Y-1.6037

N2485 X-0.2143 Y-1.6091

N2490 X-0.2261 Y-1.6179

N2495 X-0.238 Y-1.6258

N2500 X-0.2633 Y-1.6396

N2505 X-0.2684 Y-1.642

N2510 X-0.2836 Y-1.6481

N2515 X-0.2988 Y-1.6534

N2520 X-0.314 Y-1.6575

N2525 X-0.3292 Y-1.6607

N2530 X-0.3444 Y-1.6631

N2535 X-0.3596 Y-1.6643

N2540 X-0.3748 Y-1.6649

N2545 X-0.39 Y-1.6643

N2550 X-0.4052 Y-1.6631

N2555 X-0.4204 Y-1.6608

N2560 X-0.4356 Y-1.6576

N2565 X-0.4508 Y-1.6535

N2570 X-0.466 Y-1.6483

N2575 X-0.4812 Y-1.6421

N2580 X-0.4867 Y-1.6396

N2585 X-0.5117 Y-1.626

N2590 X-0.5237 Y-1.618

N2595 X-0.5421 Y-1.604

N2600 X-0.5552 Y-1.5921

N2605 X-0.5683 Y-1.5787

N2610 X-0.5725 Y-1.5739

N2615 X-0.5826 Y-1.5611

N2620 X-0.5918 Y-1.5482

N2625 X-0.6029 Y-1.5296

N2630 X-0.6091 Y-1.5178

N2635 X-0.6158 Y-1.5025

N2640 X-0.6214 Y-1.4873

N2645 X-0.626 Y-1.4721

N2650 X-0.6295 Y-1.4568

N2655 X-0.6333 Y-1.4331

N2660 X-0.6339 Y-1.4264

N2665 X-0.6349 Y-1.3959

N2670 Y-0.6041

N2675 X-0.6339 Y-0.5736

N2680 X-0.6333 Y-0.5669

N2685 X-0.6295 Y-0.5432

N2690 X-0.626 Y-0.5279

N2695 X-0.6214 Y-0.5127

N2700 X-0.6158 Y-0.4975

N2705 X-0.6091 Y-0.4822

N2710 X-0.6029 Y-0.4704

N2715 X-0.5918 Y-0.4518

N2720 X-0.5826 Y-0.4389

N2725 X-0.5725 Y-0.4261

N2730 X-0.5683 Y-0.4213

N2735 X-0.5552 Y-0.4079

N2740 X-0.5421 Y-0.396

N2745 X-0.5237 Y-0.382

N2750 X-0.5117 Y-0.374

N2755 X-0.4867 Y-0.3604

N2760 X-0.4812 Y-0.3579

N2765 X-0.466 Y-0.3517

N2770 X-0.4508 Y-0.3465

N2775 X-0.4356 Y-0.3424

N2780 X-0.4204 Y-0.3392

N2785 X-0.4052 Y-0.3369

N2790 X-0.39 Y-0.3357

N2795 X-0.3748 Y-0.3351

N2800 X-0.3596 Y-0.3357

N2805 X-0.3444 Y-0.337

N2810 X-0.3292 Y-0.3393

N2815 X-0.314 Y-0.3425

N2820 X-0.2988 Y-0.3466

N2825 X-0.2836 Y-0.3519

N2830 X-0.2684 Y-0.358

N2835 X-0.2633 Y-0.3604

N2840 X-0.238 Y-0.3742

N2845 X-0.2261 Y-0.3821

N2850 X-0.2143 Y-0.3909

N2855 X-0.2075 Y-0.3963

N2860 X-0.1946 Y-0.4081

N2865 X-0.1817 Y-0.4213

N2870 X-0.1771 Y-0.4266

N2875 X-0.1582 Y-0.4518

N2880 X-0.1467 Y-0.4712

N2885 X-0.1409 Y-0.4822

N2890 X-0.1342 Y-0.4975

N2895 X-0.1286 Y-0.5127

N2900 X-0.1239 Y-0.5279

N2905 X-0.1207 Y-0.5425

N2910 X-0.1179 Y-0.5572

N2915 X-0.1163 Y-0.5712

N2920 X-0.1152 Y-0.5888

N2925 Y-0.7258

N2930 X-0.1149 Y-0.7303 Z0.6845

N2935 X-0.1142 Y-0.7348 Z0.6849

N2940 X-0.113 Y-0.7391 Z0.6856

N2945 X-0.1114 Y-0.7432 Z0.6865

N2950 X-0.1094 Y-0.7471 Z0.6877

N2955 X-0.107 Y-0.7507 Z0.6891

N2960 X-0.1042 Y-0.7539 Z0.6907

N2965 X-0.1011 Y-0.7566 Z0.6924

N2970 X-0.0977 Y-0.759 Z0.6944

N2975 X-0.0942 Y-0.7608 Z0.6965

N2980 X-0.0904 Y-0.7622 Z0.6986

N2985 X-0.0866 Y-0.763 Z0.7008

N2990 X-0.0827 Y-0.7633 Z0.7031

N2995 X-0.079 Z0.7055

N3000 X-0.0757 Z0.7083

N3005 X-0.0727 Z0.7115

N3010 X-0.0701 Z0.715

N3015 X-0.0679 Z0.7187

N3020 X-0.0662 Z0.7228

N3025 X-0.0649 Z0.7269

N3030 X-0.0642 Z0.7312

N3035 X-0.0639 Z0.7356

N3040 G0 Z1.1969

N3045 G1 X-2.0873 Y0.2458 F500.

N3050 G0 Z0.9987

N3055 G1 Z0.725 F67.2

N3060 X-2.0874 Y0.2457 Z0.7217

N3065 X-2.0875 Y0.2452 Z0.7172

N3070 X-2.0872 Y0.2444 Z0.7128

N3075 X-2.0866 Y0.2431 Z0.7085

N3080 X-2.0856 Y0.2415 Z0.7043

N3085 X-2.0842 Y0.2396 Z0.7005

N3090 X-2.0826 Y0.2373 Z0.6969

N3095 X-2.0806 Y0.2348 Z0.6937

N3100 X-2.0783 Y0.232 Z0.691

N3105 X-2.0758 Y0.229 Z0.6886

N3110 X-2.0731 Y0.2259 Z0.6868

N3115 X-2.0703 Y0.2227 Z0.6854

N3120 X-2.0673 Y0.2194 Z0.6846

N3125 X-2.0642 Y0.216 Z0.6844

N3130 X-2.0387 Y0.1886

N3135 X-1.9024 Y0.0422

N3140 G2 X-1.6379 Y-0.6272 I-0.7219 J-0.6722

N3145 G1 X-1.6358 Y-1.3658

N3150 G2 X-1.9012 Y-2.0423 I-0.9876 J-0.0028

N3155 G1 X-2.0377 Y-2.1886

N3160 X-2.0633 Y-2.216

N3165 X-2.0664 Y-2.2193 Z0.6846

N3170 X-2.0694 Y-2.2226 Z0.6854

N3175 X-2.0722 Y-2.2259 Z0.6868

N3180 X-2.0749 Y-2.229 Z0.6886

N3185 X-2.0774 Y-2.232 Z0.691

N3190 X-2.0797 Y-2.2347 Z0.6937

N3195 X-2.0816 Y-2.2373 Z0.6969

N3200 X-2.0833 Y-2.2395 Z0.7005

N3205 X-2.0847 Y-2.2415 Z0.7043

N3210 X-2.0857 Y-2.2431 Z0.7085

N3215 X-2.0863 Y-2.2443 Z0.7128

N3220 X-2.0866 Y-2.2452 Z0.7172

N3225 X-2.0865 Y-2.2457 Z0.7217

N3230 X-2.0864 Y-2.2458 Z0.725

N3235 G0 Z1.1969

N3240 G1 X-3.2525 Y-0.1357 F500.

N3245 G0 Z0.9987

N3250 G1 Z0.725 F67.2

N3255 X-3.2524 Y-0.1358 Z0.7217

N3260 X-3.2519 Y-0.136 Z0.7172

N3265 X-3.251 Y-0.1359 Z0.7128

N3270 X-3.2497 Y-0.1354 Z0.7085

N3275 X-3.248 Y-0.1347 Z0.7043

N3280 X-3.2458 Y-0.1336 Z0.7005

N3285 X-3.2434 Y-0.1323 Z0.6969

N3290 X-3.2406 Y-0.1307 Z0.6937

N3295 X-3.2375 Y-0.1289 Z0.691

N3300 X-3.2342 Y-0.1269 Z0.6886

N3305 X-3.2307 Y-0.1247 Z0.6868

N3310 X-3.227 Y-0.1224 Z0.6854

N3315 X-3.2233 Y-0.1199 Z0.6846

N3320 X-3.2196 Y-0.1174 Z0.6844

N3325 X-3.1886 Y-0.0963

N3330 X-3.0536 Y-0.0041

N3335 G2 X-2.6283 Y0.1275 I0.4263 J-0.6246

N3340 G1 X-2.6265

N3345 G2 X-2.0919 Y-0.0929 I0.001 J-0.7562

N3350 G1 X-2.0907 Y-0.0941

N3355 G2 X-1.8681 Y-0.6278 I-0.5336 J-0.5358

N3360 G1 X-1.866 Y-1.3664

N3365 G2 X-2.0867 Y-1.903 I-0.7574 J-0.0022

N3370 G1 X-2.088 Y-1.9043

N3375 G2 X-2.6236 Y-2.1272 I-0.5367 J0.5344

N3380 G1 X-2.6254

N3385 G2 X-3.0535 Y-1.9953 I-0.001 J0.7574

N3390 G1 X-3.1886 Y-1.903

N3395 G3 X-3.2024 Y-1.9206 I-0.0063 J-0.0093

N3400 G1 X-2.9775 Y-2.1232

N3405 G3 X-2.9022 Y-2.0752 I0.031 J0.0344

N3410 G2 X-2.9347 Y-1.8969 I0.7496 J0.229

N3415 G3 X-3.0074 Y-1.7308 I-0.2654 J-0.0172

N3420 G2 X-3.1524 Y-1.3676 I0.3819 J0.3631

N3425 G1 X-3.1522 Y-0.6307

N3430 G2 X-2.1007 Y-0.6294 I0.5258 J-0.0002

N3435 G1 X-2.0985 Y-1.3662

N3440 G2 X-3.0074 Y-1.7308 I-0.5269 J-0.0015

N3445 X-2.9909 Y-1.486 I0.1208 J0.1148

N3450 G3 X-2.8848 Y-1.2647 I-0.1776 J0.2212

N3455 G1 Y-0.5888

N3460 X-2.8837 Y-0.5712

N3465 X-2.8821 Y-0.5572

N3470 X-2.8793 Y-0.5425

N3475 X-2.8761 Y-0.5279

N3480 X-2.8714 Y-0.5127

N3485 X-2.8658 Y-0.4975

N3490 X-2.8591 Y-0.4822

N3495 X-2.8533 Y-0.4712

N3500 X-2.8418 Y-0.4518

N3505 X-2.8327 Y-0.4392

N3510 X-2.8229 Y-0.4266

N3515 X-2.8183 Y-0.4213

N3520 X-2.8054 Y-0.4081

N3525 X-2.7925 Y-0.3963

N3530 X-2.7857 Y-0.3909

N3535 X-2.7739 Y-0.3821

N3540 X-2.762 Y-0.3742

N3545 X-2.7367 Y-0.3604

N3550 X-2.7316 Y-0.358

N3555 X-2.7164 Y-0.3519

N3560 X-2.7012 Y-0.3466

N3565 X-2.686 Y-0.3425

N3570 X-2.6708 Y-0.3393

N3575 X-2.6556 Y-0.337

N3580 X-2.6404 Y-0.3357

N3585 X-2.6252 Y-0.3351

N3590 X-2.61 Y-0.3357

N3595 X-2.5948 Y-0.3369

N3600 X-2.5796 Y-0.3392

N3605 X-2.5644 Y-0.3424

N3610 X-2.5492 Y-0.3465

N3615 X-2.534 Y-0.3517

N3620 X-2.5188 Y-0.3579

N3625 X-2.5133 Y-0.3604

N3630 X-2.4883 Y-0.374

N3635 X-2.4763 Y-0.382

N3640 X-2.4579 Y-0.396

N3645 X-2.4448 Y-0.4079

N3650 X-2.4317 Y-0.4213

N3655 X-2.4275 Y-0.4261

N3660 X-2.4174 Y-0.4389

N3665 X-2.4082 Y-0.4518

N3670 X-2.3971 Y-0.4704

N3675 X-2.3909 Y-0.4822

N3680 X-2.3842 Y-0.4975

N3685 X-2.3786 Y-0.5127

N3690 X-2.374 Y-0.5279

N3695 X-2.3705 Y-0.5432

N3700 X-2.3667 Y-0.5669

N3705 X-2.3661 Y-0.5736

N3710 X-2.3651 Y-0.6041

N3715 Y-1.3959

N3720 X-2.3661 Y-1.4264

N3725 X-2.3667 Y-1.4331

N3730 X-2.3705 Y-1.4568

N3735 X-2.374 Y-1.4721

N3740 X-2.3786 Y-1.4873

N3745 X-2.3842 Y-1.5025

N3750 X-2.3909 Y-1.5178

N3755 X-2.3971 Y-1.5296

N3760 X-2.4082 Y-1.5482

N3765 X-2.4174 Y-1.5611

N3770 X-2.4275 Y-1.5739

N3775 X-2.4317 Y-1.5787

N3780 X-2.4448 Y-1.5921

N3785 X-2.4579 Y-1.604

N3790 X-2.4763 Y-1.618

N3795 X-2.4883 Y-1.626

N3800 X-2.5133 Y-1.6396

N3805 X-2.5188 Y-1.6421

N3810 X-2.534 Y-1.6483

N3815 X-2.5492 Y-1.6535

N3820 X-2.5644 Y-1.6576

N3825 X-2.5796 Y-1.6608

N3830 X-2.5948 Y-1.6631

N3835 X-2.61 Y-1.6643

N3840 X-2.6252 Y-1.6649

N3845 X-2.6404 Y-1.6643

N3850 X-2.6556 Y-1.6631

N3855 X-2.6708 Y-1.6607

N3860 X-2.686 Y-1.6575

N3865 X-2.7012 Y-1.6534

N3870 X-2.7164 Y-1.6481

N3875 X-2.7316 Y-1.642

N3880 X-2.7367 Y-1.6396

N3885 X-2.762 Y-1.6258

N3890 X-2.7739 Y-1.6179

N3895 X-2.7857 Y-1.6091

N3900 X-2.7925 Y-1.6037

N3905 X-2.8054 Y-1.5919

N3910 X-2.8183 Y-1.5787

N3915 X-2.8229 Y-1.5734

N3920 X-2.8327 Y-1.5608

N3925 X-2.8418 Y-1.5482

N3930 X-2.8533 Y-1.5288

N3935 X-2.8591 Y-1.5178

N3940 X-2.8658 Y-1.5025

N3945 X-2.8714 Y-1.4873

N3950 X-2.8761 Y-1.4721

N3955 X-2.8793 Y-1.4575

N3960 X-2.8821 Y-1.4428

N3965 X-2.8837 Y-1.4288

N3970 X-2.8848 Y-1.4112

N3975 Y-1.2647

N3980 X-2.8851 Y-1.2602 Z0.6845

N3985 X-2.8858 Y-1.2558 Z0.6849

N3990 X-2.887 Y-1.2514 Z0.6856

N3995 X-2.8886 Y-1.2473 Z0.6865

N4000 X-2.8906 Y-1.2434 Z0.6877

N4005 X-2.893 Y-1.2399 Z0.6891

N4010 X-2.8958 Y-1.2367 Z0.6907

N4015 X-2.8989 Y-1.2339 Z0.6924

N4020 X-2.9023 Y-1.2315 Z0.6944

N4025 X-2.9058 Y-1.2297 Z0.6965

N4030 X-2.9096 Y-1.2283 Z0.6986

N4035 X-2.9134 Y-1.2275 Z0.7008

N4040 X-2.9173 Y-1.2273 Z0.7031

N4045 X-2.921 Z0.7055

N4050 X-2.9243 Z0.7083

N4055 X-2.9273 Z0.7115

N4060 X-2.9299 Z0.715

N4065 X-2.9321 Z0.7187

N4070 X-2.9338 Z0.7228

N4075 X-2.9351 Z0.7269

N4080 X-2.9358 Z0.7312

N4085 X-2.9361 Z0.7356

N4090 G0 Z1.0381

N4095 G1 X-1.2456 Y-2.2526 F500.

N4100 G0 Z0.7643

N4105 G1 Z0.4906 F67.2

N4110 X-1.2455 Y-2.2525 Z0.4874

N4115 X-1.2453 Y-2.2521 Z0.4829

N4120 X-1.2454 Y-2.2512 Z0.4784

N4125 X-1.2458 Y-2.2498 Z0.4741

N4130 X-1.2465 Y-2.2481 Z0.47

N4135 X-1.2474 Y-2.2459 Z0.4661

N4140 X-1.2486 Y-2.2433 Z0.4626

N4145 X-1.2501 Y-2.2405 Z0.4594

N4150 X-1.2518 Y-2.2373 Z0.4566

N4155 X-1.2536 Y-2.2339 Z0.4543

N4160 X-1.2557 Y-2.2303 Z0.4524

N4165 X-1.2579 Y-2.2266 Z0.4511

N4170 X-1.2602 Y-2.2228 Z0.4503

N4175 X-1.2625 Y-2.2189 Z0.45

N4180 X-1.2824 Y-2.1871

N4185 X-1.4114 Y-1.9799

N4190 X-1.4439 Y-1.9246

N4195 G3 X-1.5542 I-0.0552 J-0.0325

N4200 G1 X-1.6035 Y-2.0074

N4205 X-1.7161 Y-2.1871

N4210 X-1.736 Y-2.2189

N4215 X-1.7383 Y-2.2227 Z0.4503

N4220 X-1.7406 Y-2.2265 Z0.4511

N4225 X-1.7428 Y-2.2303 Z0.4524

N4230 X-1.7449 Y-2.2339 Z0.4543

N4235 X-1.7468 Y-2.2373 Z0.4566

N4240 X-1.7485 Y-2.2404 Z0.4594

N4245 X-1.7499 Y-2.2433 Z0.4626

N4250 X-1.7511 Y-2.2458 Z0.4661

N4255 X-1.7521 Y-2.248 Z0.47

N4260 X-1.7528 Y-2.2497 Z0.4741

N4265 X-1.7532 Y-2.2511 Z0.4784

N4270 X-1.7533 Y-2.252 Z0.4829

N4275 X-1.7531 Y-2.2524 Z0.4874

N4280 X-1.753 Y-2.2525 Z0.4906

N4285 G0 Z1.0381

N4290 G1 X-1.7555 Y0.254 F500.

N4295 G0 Z0.7643

N4300 G1 Z0.4906 F67.2

N4305 X-1.7556 Y0.2539 Z0.4874

N4310 X-1.7558 Y0.2535 Z0.4829

N4315 X-1.7557 Y0.2526 Z0.4784

N4320 X-1.7553 Y0.2512 Z0.4741

N4325 X-1.7546 Y0.2495 Z0.47

N4330 X-1.7536 Y0.2473 Z0.4661

N4335 X-1.7524 Y0.2448 Z0.4626

N4340 X-1.751 Y0.2419 Z0.4594

N4345 X-1.7493 Y0.2388 Z0.4566

N4350 X-1.7474 Y0.2354 Z0.4543

N4355 X-1.7453 Y0.2318 Z0.4524

N4360 X-1.7431 Y0.228 Z0.4511

N4365 X-1.7408 Y0.2242 Z0.4503

N4370 X-1.7385 Y0.2204 Z0.45

N4375 X-1.7186 Y0.1886

N4380 X-1.5891 Y-0.0187

N4385 X-1.5565 Y-0.0739

N4390 G3 X-1.4461 I0.0552 J0.0326

N4395 G1 X-1.3966 Y0.009

N4400 X-1.284 Y0.1886

N4405 X-1.264 Y0.2203

N4410 X-1.2616 Y0.2242 Z0.4503

N4415 X-1.2593 Y0.228 Z0.4511

N4420 X-1.2571 Y0.2317 Z0.4524

N4425 X-1.2551 Y0.2353 Z0.4543

N4430 X-1.2532 Y0.2387 Z0.4566

N4435 X-1.2515 Y0.2418 Z0.4594

N4440 X-1.25 Y0.2447 Z0.4626

N4445 X-1.2488 Y0.2472 Z0.4661

N4450 X-1.2479 Y0.2494 Z0.47

N4455 X-1.2472 Y0.2512 Z0.4741

N4460 X-1.2468 Y0.2525 Z0.4784

N4465 X-1.2467 Y0.2534 Z0.4829

N4470 X-1.2469 Y0.2538 Z0.4874

N4475 X-1.247 Y0.2539 Z0.4906

N4480 G0 Z1.0381

N4485 G1 X-0.9123 Y-2.2458 F500.

N4490 G0 Z0.7643

N4495 G1 Z0.4906 F67.2

N4500 X-0.9122 Y-2.2457 Z0.4874

N4505 X-0.9121 Y-2.2452 Z0.4829

N4510 X-0.9124 Y-2.2444 Z0.4784

N4515 X-0.913 Y-2.2431 Z0.4741

N4520 X-0.914 Y-2.2415 Z0.47

N4525 X-0.9154 Y-2.2396 Z0.4661

N4530 X-0.917 Y-2.2373 Z0.4626

N4535 X-0.919 Y-2.2348 Z0.4594

N4540 X-0.9213 Y-2.232 Z0.4566

N4545 X-0.9238 Y-2.229 Z0.4543

N4550 X-0.9264 Y-2.2259 Z0.4524

N4555 X-0.9293 Y-2.2227 Z0.4511

N4560 X-0.9323 Y-2.2193 Z0.4503

N4565 X-0.9354 Y-2.216 Z0.45

N4570 X-0.9609 Y-2.1886

N4575 X-1.0972 Y-2.0423

N4580 G2 X-1.3618 Y-1.3741 I0.7217 J0.6722

N4585 G1 X-1.3648 Y-0.6342

N4590 G2 X-1.1002 Y0.0422 I0.9866 J0.004

N4595 G1 X-0.9639 Y0.1886

N4600 X-0.9383 Y0.216

N4605 X-0.9353 Y0.2194 Z0.4503

N4610 X-0.9323 Y0.2227 Z0.4511

N4615 X-0.9294 Y0.2259 Z0.4524

N4620 X-0.9267 Y0.229 Z0.4543

N4625 X-0.9242 Y0.232 Z0.4566

N4630 X-0.922 Y0.2348 Z0.4594

N4635 X-0.92 Y0.2373 Z0.4626

N4640 X-0.9183 Y0.2396 Z0.4661

N4645 X-0.917 Y0.2415 Z0.47

N4650 X-0.916 Y0.2431 Z0.4741

N4655 X-0.9153 Y0.2444 Z0.4784

N4660 X-0.9151 Y0.2452 Z0.4829

N4665 X-0.9152 Y0.2457 Z0.4874

N4670 X-0.9153 Y0.2458 Z0.4906

N4675 G0 Z1.0381

N4680 G1 X0.2525 Y-1.8643 F500.

N4685 G0 Z0.7643

N4690 G1 Z0.4906 F67.2

N4695 X0.2524 Y-1.8642 Z0.4874

N4700 X0.2519 Y-1.864 Z0.4829

N4705 X0.251 Y-1.8641 Z0.4784

N4710 X0.2497 Y-1.8646 Z0.4741

N4715 X0.248 Y-1.8653 Z0.47

N4720 X0.2458 Y-1.8664 Z0.4661

N4725 X0.2434 Y-1.8677 Z0.4626

N4730 X0.2406 Y-1.8693 Z0.4594

N4735 X0.2375 Y-1.8711 Z0.4566

N4740 X0.2342 Y-1.8731 Z0.4543

N4745 X0.2307 Y-1.8753 Z0.4524

N4750 X0.227 Y-1.8776 Z0.4511

N4755 X0.2233 Y-1.8801 Z0.4503

N4760 X0.2196 Y-1.8826 Z0.45

N4765 X0.1886 Y-1.9037

N4770 X0.0536 Y-1.9958

N4775 G2 X-0.3698 Y-2.1273 I-0.4261 J0.6245

N4780 G1 X-0.3716

N4785 G2 X-0.9068 Y-1.908 I-0.0027 J0.7561

N4790 G1 X-0.9081 Y-1.9067

N4795 G2 X-1.1316 Y-1.3731 I0.5326 J0.5367

N4800 G1 X-1.1346 Y-0.6332

N4805 G2 X-0.9151 Y-0.0974 I0.7564 J0.0031

N4810 G1 X-0.9138 Y-0.0961

N4815 G2 X-0.3796 Y0.1275 I0.5369 J-0.5328

N4820 G1 X-0.3779

N4825 G2 X0.054 Y-0.006 I0.0027 J-0.7564

N4830 G1 X0.1886 Y-0.0988

N4835 G3 X0.2025 Y-0.0812 I0.0064 J0.0092

N4840 G1 X-0.0215 Y0.1222

N4845 G3 X-0.0971 Y0.0745 I-0.0312 J-0.0343

N4850 G2 X-0.0653 Y-0.1039 I-0.7503 J-0.2257

N4855 G3 X0.0067 Y-0.2702 I0.2654 J0.0161

N4860 G2 X0.1499 Y-0.6294 I-0.3827 J-0.3608

N4865 G1 X0.1522 Y-1.3675

N4870 G2 X-0.899 Y-1.3713 I-0.5256 J-0.0016

N4875 G1 X-0.902 Y-0.6332

N4880 G2 X0.0067 Y-0.2702 I0.526 J0.0021

N4885 X-0.0107 Y-0.5097 I-0.1185 J-0.1117

N4890 G3 X-0.1152 Y-0.7258 I0.1713 J-0.2161

N4895 G1 Y-1.4112

N4900 X-0.1163 Y-1.4288

N4905 X-0.1179 Y-1.4428

N4910 X-0.1207 Y-1.4575

N4915 X-0.1239 Y-1.4721

N4920 X-0.1286 Y-1.4873

N4925 X-0.1342 Y-1.5025

N4930 X-0.1409 Y-1.5178

N4935 X-0.1467 Y-1.5288

N4940 X-0.1582 Y-1.5482

N4945 X-0.1771 Y-1.5734

N4950 X-0.1817 Y-1.5787

N4955 X-0.1946 Y-1.5919

N4960 X-0.2075 Y-1.6037

N4965 X-0.2143 Y-1.6091

N4970 X-0.2261 Y-1.6179

N4975 X-0.238 Y-1.6258

N4980 X-0.2633 Y-1.6396

N4985 X-0.2684 Y-1.642

N4990 X-0.2836 Y-1.6481

N4995 X-0.2988 Y-1.6534

N5000 X-0.314 Y-1.6575

N5005 X-0.3292 Y-1.6607

N5010 X-0.3444 Y-1.6631

N5015 X-0.3596 Y-1.6643

N5020 X-0.3748 Y-1.6649

N5025 X-0.39 Y-1.6643

N5030 X-0.4052 Y-1.6631

N5035 X-0.4204 Y-1.6608

N5040 X-0.4356 Y-1.6576

N5045 X-0.4508 Y-1.6535

N5050 X-0.466 Y-1.6483

N5055 X-0.4812 Y-1.6421

N5060 X-0.4867 Y-1.6396

N5065 X-0.5117 Y-1.626

N5070 X-0.5237 Y-1.618

N5075 X-0.5421 Y-1.604

N5080 X-0.5552 Y-1.5921

N5085 X-0.5683 Y-1.5787

N5090 X-0.5725 Y-1.5739

N5095 X-0.5826 Y-1.5611

N5100 X-0.5918 Y-1.5482

N5105 X-0.6029 Y-1.5296

N5110 X-0.6091 Y-1.5178

N5115 X-0.6158 Y-1.5025

N5120 X-0.6214 Y-1.4873

N5125 X-0.626 Y-1.4721

N5130 X-0.6295 Y-1.4568

N5135 X-0.6333 Y-1.4331

N5140 X-0.6339 Y-1.4264

N5145 X-0.6349 Y-1.3959

N5150 Y-0.6041

N5155 X-0.6339 Y-0.5736

N5160 X-0.6333 Y-0.5669

N5165 X-0.6295 Y-0.5432

N5170 X-0.626 Y-0.5279

N5175 X-0.6214 Y-0.5127

N5180 X-0.6158 Y-0.4975

N5185 X-0.6091 Y-0.4822

N5190 X-0.6029 Y-0.4704

N5195 X-0.5918 Y-0.4518

N5200 X-0.5826 Y-0.4389

N5205 X-0.5725 Y-0.4261

N5210 X-0.5683 Y-0.4213

N5215 X-0.5552 Y-0.4079

N5220 X-0.5421 Y-0.396

N5225 X-0.5237 Y-0.382

N5230 X-0.5117 Y-0.374

N5235 X-0.4867 Y-0.3604

N5240 X-0.4812 Y-0.3579

N5245 X-0.466 Y-0.3517

N5250 X-0.4508 Y-0.3465

N5255 X-0.4356 Y-0.3424

N5260 X-0.4204 Y-0.3392

N5265 X-0.4052 Y-0.3369

N5270 X-0.39 Y-0.3357

N5275 X-0.3748 Y-0.3351

N5280 X-0.3596 Y-0.3357

N5285 X-0.3444 Y-0.337

N5290 X-0.3292 Y-0.3393

N5295 X-0.314 Y-0.3425

N5300 X-0.2988 Y-0.3466

N5305 X-0.2836 Y-0.3519

N5310 X-0.2684 Y-0.358

N5315 X-0.2633 Y-0.3604

N5320 X-0.238 Y-0.3742

N5325 X-0.2261 Y-0.3821

N5330 X-0.2143 Y-0.3909

N5335 X-0.2075 Y-0.3963

N5340 X-0.1946 Y-0.4081

N5345 X-0.1817 Y-0.4213

N5350 X-0.1771 Y-0.4266

N5355 X-0.1582 Y-0.4518

N5360 X-0.1467 Y-0.4712

N5365 X-0.1409 Y-0.4822

N5370 X-0.1342 Y-0.4975

N5375 X-0.1286 Y-0.5127

N5380 X-0.1239 Y-0.5279

N5385 X-0.1207 Y-0.5425

N5390 X-0.1179 Y-0.5572

N5395 X-0.1163 Y-0.5712

N5400 X-0.1152 Y-0.5888

N5405 Y-0.7258

N5410 X-0.1149 Y-0.7303 Z0.4501

N5415 X-0.1142 Y-0.7348 Z0.4505

N5420 X-0.113 Y-0.7391 Z0.4512

N5425 X-0.1114 Y-0.7432 Z0.4521

N5430 X-0.1094 Y-0.7471 Z0.4533

N5435 X-0.107 Y-0.7507 Z0.4547

N5440 X-0.1042 Y-0.7539 Z0.4563

N5445 X-0.1011 Y-0.7566 Z0.4581

N5450 X-0.0977 Y-0.759 Z0.46

N5455 X-0.0942 Y-0.7608 Z0.4621

N5460 X-0.0904 Y-0.7622 Z0.4643

N5465 X-0.0866 Y-0.763 Z0.4665

N5470 X-0.0827 Y-0.7633 Z0.4688

N5475 X-0.079 Z0.4711

N5480 X-0.0757 Z0.4739

N5485 X-0.0727 Z0.4771

N5490 X-0.0701 Z0.4806

N5495 X-0.0679 Z0.4844

N5500 X-0.0662 Z0.4884

N5505 X-0.0649 Z0.4926

N5510 X-0.0642 Z0.4969

N5515 X-0.0639 Z0.5012

N5520 G0 Z1.0381

N5525 G1 X-2.0873 Y0.2458 F500.

N5530 G0 Z0.7643

N5535 G1 Z0.4906 F67.2

N5540 X-2.0874 Y0.2457 Z0.4874

N5545 X-2.0875 Y0.2452 Z0.4829

N5550 X-2.0872 Y0.2444 Z0.4784

N5555 X-2.0866 Y0.2431 Z0.4741

N5560 X-2.0856 Y0.2415 Z0.47

N5565 X-2.0842 Y0.2396 Z0.4661

N5570 X-2.0826 Y0.2373 Z0.4626

N5575 X-2.0806 Y0.2348 Z0.4594

N5580 X-2.0783 Y0.232 Z0.4566

N5585 X-2.0758 Y0.229 Z0.4543

N5590 X-2.0731 Y0.2259 Z0.4524

N5595 X-2.0703 Y0.2227 Z0.4511

N5600 X-2.0673 Y0.2194 Z0.4503

N5605 X-2.0642 Y0.216 Z0.45

N5610 X-2.0387 Y0.1886

N5615 X-1.9024 Y0.0422

N5620 G2 X-1.6379 Y-0.6272 I-0.7219 J-0.6722

N5625 G1 X-1.6358 Y-1.3658

N5630 G2 X-1.9012 Y-2.0423 I-0.9876 J-0.0028

N5635 G1 X-2.0377 Y-2.1886

N5640 X-2.0633 Y-2.216

N5645 X-2.0664 Y-2.2193 Z0.4503

N5650 X-2.0694 Y-2.2226 Z0.4511

N5655 X-2.0722 Y-2.2259 Z0.4524

N5660 X-2.0749 Y-2.229 Z0.4543

N5665 X-2.0774 Y-2.232 Z0.4566

N5670 X-2.0797 Y-2.2347 Z0.4594

N5675 X-2.0816 Y-2.2373 Z0.4626

N5680 X-2.0833 Y-2.2395 Z0.4661

N5685 X-2.0847 Y-2.2415 Z0.47

N5690 X-2.0857 Y-2.2431 Z0.4741

N5695 X-2.0863 Y-2.2443 Z0.4784

N5700 X-2.0866 Y-2.2452 Z0.4829

N5705 X-2.0865 Y-2.2457 Z0.4874

N5710 X-2.0864 Y-2.2458 Z0.4906

N5715 G0 Z1.0381

N5720 G1 X-3.2525 Y-0.1357 F500.

N5725 G0 Z0.7643

N5730 G1 Z0.4906 F67.2

N5735 X-3.2524 Y-0.1358 Z0.4874

N5740 X-3.2519 Y-0.136 Z0.4829

N5745 X-3.251 Y-0.1359 Z0.4784

N5750 X-3.2497 Y-0.1354 Z0.4741

N5755 X-3.248 Y-0.1347 Z0.47

N5760 X-3.2458 Y-0.1336 Z0.4661

N5765 X-3.2434 Y-0.1323 Z0.4626

N5770 X-3.2406 Y-0.1307 Z0.4594

N5775 X-3.2375 Y-0.1289 Z0.4566

N5780 X-3.2342 Y-0.1269 Z0.4543

N5785 X-3.2307 Y-0.1247 Z0.4524

N5790 X-3.227 Y-0.1224 Z0.4511

N5795 X-3.2233 Y-0.1199 Z0.4503

N5800 X-3.2196 Y-0.1174 Z0.45

N5805 X-3.1886 Y-0.0963

N5810 X-3.0536 Y-0.0041

N5815 G2 X-2.6283 Y0.1275 I0.4263 J-0.6246

N5820 G1 X-2.6265

N5825 G2 X-2.0919 Y-0.0929 I0.001 J-0.7562

N5830 G1 X-2.0907 Y-0.0941

N5835 G2 X-1.8681 Y-0.6278 I-0.5336 J-0.5358

N5840 G1 X-1.866 Y-1.3664

N5845 G2 X-2.0867 Y-1.903 I-0.7574 J-0.0022

N5850 G1 X-2.088 Y-1.9043

N5855 G2 X-2.6236 Y-2.1272 I-0.5367 J0.5344

N5860 G1 X-2.6254

N5865 G2 X-3.0535 Y-1.9953 I-0.001 J0.7574

N5870 G1 X-3.1886 Y-1.903

N5875 G3 X-3.2024 Y-1.9206 I-0.0063 J-0.0093

N5880 G1 X-2.9775 Y-2.1232

N5885 G3 X-2.9022 Y-2.0752 I0.031 J0.0344

N5890 G2 X-2.9347 Y-1.8969 I0.7496 J0.229

N5895 G3 X-3.0074 Y-1.7308 I-0.2654 J-0.0172

N5900 G2 X-3.1524 Y-1.3676 I0.3819 J0.3631

N5905 G1 X-3.1522 Y-0.6307

N5910 G2 X-2.1007 Y-0.6294 I0.5258 J-0.0002

N5915 G1 X-2.0985 Y-1.3662

N5920 G2 X-3.0074 Y-1.7308 I-0.5269 J-0.0015

N5925 X-2.9909 Y-1.486 I0.1208 J0.1148

N5930 G3 X-2.8848 Y-1.2647 I-0.1776 J0.2212

N5935 G1 Y-0.5888

N5940 X-2.8837 Y-0.5712

N5945 X-2.8821 Y-0.5572

N5950 X-2.8793 Y-0.5425

N5955 X-2.8761 Y-0.5279

N5960 X-2.8714 Y-0.5127

N5965 X-2.8658 Y-0.4975

N5970 X-2.8591 Y-0.4822

N5975 X-2.8533 Y-0.4712

N5980 X-2.8418 Y-0.4518

N5985 X-2.8327 Y-0.4392

N5990 X-2.8229 Y-0.4266

N5995 X-2.8183 Y-0.4213

N6000 X-2.8054 Y-0.4081

N6005 X-2.7925 Y-0.3963

N6010 X-2.7857 Y-0.3909

N6015 X-2.7739 Y-0.3821

N6020 X-2.762 Y-0.3742

N6025 X-2.7367 Y-0.3604

N6030 X-2.7316 Y-0.358

N6035 X-2.7164 Y-0.3519

N6040 X-2.7012 Y-0.3466

N6045 X-2.686 Y-0.3425

N6050 X-2.6708 Y-0.3393

N6055 X-2.6556 Y-0.337

N6060 X-2.6404 Y-0.3357

N6065 X-2.6252 Y-0.3351

N6070 X-2.61 Y-0.3357

N6075 X-2.5948 Y-0.3369

N6080 X-2.5796 Y-0.3392

N6085 X-2.5644 Y-0.3424

N6090 X-2.5492 Y-0.3465

N6095 X-2.534 Y-0.3517

N6100 X-2.5188 Y-0.3579

N6105 X-2.5133 Y-0.3604

N6110 X-2.4883 Y-0.374

N6115 X-2.4763 Y-0.382

N6120 X-2.4579 Y-0.396

N6125 X-2.4448 Y-0.4079

N6130 X-2.4317 Y-0.4213

N6135 X-2.4275 Y-0.4261

N6140 X-2.4174 Y-0.4389

N6145 X-2.4082 Y-0.4518

N6150 X-2.3971 Y-0.4704

N6155 X-2.3909 Y-0.4822

N6160 X-2.3842 Y-0.4975

N6165 X-2.3786 Y-0.5127

N6170 X-2.374 Y-0.5279

N6175 X-2.3705 Y-0.5432

N6180 X-2.3667 Y-0.5669

N6185 X-2.3661 Y-0.5736

N6190 X-2.3651 Y-0.6041

N6195 Y-1.3959

N6200 X-2.3661 Y-1.4264

N6205 X-2.3667 Y-1.4331

N6210 X-2.3705 Y-1.4568

N6215 X-2.374 Y-1.4721

N6220 X-2.3786 Y-1.4873

N6225 X-2.3842 Y-1.5025

N6230 X-2.3909 Y-1.5178

N6235 X-2.3971 Y-1.5296

N6240 X-2.4082 Y-1.5482

N6245 X-2.4174 Y-1.5611

N6250 X-2.4275 Y-1.5739

N6255 X-2.4317 Y-1.5787

N6260 X-2.4448 Y-1.5921

N6265 X-2.4579 Y-1.604

N6270 X-2.4763 Y-1.618

N6275 X-2.4883 Y-1.626

N6280 X-2.5133 Y-1.6396

N6285 X-2.5188 Y-1.6421

N6290 X-2.534 Y-1.6483

N6295 X-2.5492 Y-1.6535

N6300 X-2.5644 Y-1.6576

N6305 X-2.5796 Y-1.6608

N6310 X-2.5948 Y-1.6631

N6315 X-2.61 Y-1.6643

N6320 X-2.6252 Y-1.6649

N6325 X-2.6404 Y-1.6643

N6330 X-2.6556 Y-1.6631

N6335 X-2.6708 Y-1.6607

N6340 X-2.686 Y-1.6575

N6345 X-2.7012 Y-1.6534

N6350 X-2.7164 Y-1.6481

N6355 X-2.7316 Y-1.642

N6360 X-2.7367 Y-1.6396

N6365 X-2.762 Y-1.6258

N6370 X-2.7739 Y-1.6179

N6375 X-2.7857 Y-1.6091

N6380 X-2.7925 Y-1.6037

N6385 X-2.8054 Y-1.5919

N6390 X-2.8183 Y-1.5787

N6395 X-2.8229 Y-1.5734

N6400 X-2.8327 Y-1.5608

N6405 X-2.8418 Y-1.5482

N6410 X-2.8533 Y-1.5288

N6415 X-2.8591 Y-1.5178

N6420 X-2.8658 Y-1.5025

N6425 X-2.8714 Y-1.4873

N6430 X-2.8761 Y-1.4721

N6435 X-2.8793 Y-1.4575

N6440 X-2.8821 Y-1.4428

N6445 X-2.8837 Y-1.4288

N6450 X-2.8848 Y-1.4112

N6455 Y-1.2647

N6460 X-2.8851 Y-1.2602 Z0.4501

N6465 X-2.8858 Y-1.2558 Z0.4505

N6470 X-2.887 Y-1.2514 Z0.4512

N6475 X-2.8886 Y-1.2473 Z0.4521

N6480 X-2.8906 Y-1.2434 Z0.4533

N6485 X-2.893 Y-1.2399 Z0.4547

N6490 X-2.8958 Y-1.2367 Z0.4563

N6495 X-2.8989 Y-1.2339 Z0.4581

N6500 X-2.9023 Y-1.2315 Z0.46

N6505 X-2.9058 Y-1.2297 Z0.4621

N6510 X-2.9096 Y-1.2283 Z0.4643

N6515 X-2.9134 Y-1.2275 Z0.4665

N6520 X-2.9173 Y-1.2273 Z0.4688

N6525 X-2.921 Z0.4711

N6530 X-2.9243 Z0.4739

N6535 X-2.9273 Z0.4771

N6540 X-2.9299 Z0.4806

N6545 X-2.9321 Z0.4844

N6550 X-2.9338 Z0.4884

N6555 X-2.9351 Z0.4926

N6560 X-2.9358 Z0.4969

N6565 X-2.9361 Z0.5012

N6570 G0 Z1.5906

(2D Pocket3)

N6575 S7500 M3

N6580 G1 X-1.5719 Y0.2229 F500.

N6585 G0 Z1.5906

N6590 Z1.1969

N6595 G1 Z0.0337 F67.2

N6600 Y0.2227 Z0.0293

N6605 X-1.572 Y0.2218 Z0.025

N6610 X-1.5723 Y0.2204 Z0.0208

N6615 X-1.5726 Y0.2185 Z0.0169

N6620 X-1.573 Y0.216 Z0.0132

N6625 X-1.5734 Y0.2132 Z0.0099

N6630 X-1.5739 Y0.2099 Z0.007

N6635 X-1.5745 Y0.2063 Z0.0045

N6640 X-1.5751 Y0.2024 Z0.0026

N6645 X-1.5758 Y0.1982 Z0.0012

N6650 X-1.5765 Y0.194 Z0.0003

N6655 X-1.5771 Y0.1896 Z0.

N6660 X-1.5772 Y0.1893

N6665 X-1.5775 Y0.1864

N6670 X-1.5777 Y0.1834

N6675 Y0.

N6680 Y-0.1527

N6685 X-1.4223

N6690 Y0.1833

N6695 X-1.4225 Y0.1863

N6700 X-1.4228 Y0.1892

N6705 X-1.423 Y0.1907

N6710 X-1.4237 Y0.1951 Z0.0003

N6715 X-1.4244 Y0.1995 Z0.0011

N6720 X-1.4251 Y0.2038 Z0.0024

N6725 X-1.4258 Y0.2079 Z0.0043

N6730 X-1.4264 Y0.2117 Z0.0066

N6735 X-1.4269 Y0.2152 Z0.0094

N6740 X-1.4274 Y0.2184 Z0.0126

N6745 X-1.4279 Y0.2211 Z0.0162

N6750 X-1.4282 Y0.2235 Z0.0201

N6755 X-1.4285 Y0.2253 Z0.0242

N6760 X-1.4287 Y0.2266 Z0.0285

N6765 X-1.4289 Y0.2274 Z0.033

N6770 Y0.2277 Z0.0375

N6775 G0 Z1.5906

N6780 M9

N6785 M5

N6790 G53 G0 Z0.

(2D Contour3 2)

N6795 M1

N6800 T1 M6

N6805 S8500 M3

N6810 G17 G90

N6815 G54

N6820 M8

N6825 G1 X-2.6375 Y-0.42 F500.

N6830 G0 G43 Z1.5906 H1

N6835 T6

N6840 G0 Z1.1969

N6845 G1 Z1.025 F26.4

N6850 Z0.4625

N6855 G19 G2 Y-0.4325 Z0.45 J-0.0125 K0.

N6860 G1 Y-0.445

N6865 G17 G3 X-2.625 Y-0.4575 I0.0125 J0.

N6870 G2 X-2.4875 Y-0.595 I0. J-0.1375

N6875 G1 Y-1.405

N6880 G2 X-2.7625 I-0.1375 J0.

N6885 G1 Y-0.595

N6890 G2 X-2.625 Y-0.4575 I0.1375 J0.

N6895 X-2.6154 Y-0.4641 I0. J-0.0103

N6900 G3 X-2.6063 Y-0.4714 I0.0108 J0.0041

N6905 G2 X-2.5 Y-0.595 I-0.0187 J-0.1236

N6910 G1 Y-1.405

N6915 G2 X-2.75 I-0.125 J0.

N6920 G1 Y-0.595

N6925 G2 X-2.6063 Y-0.4714 I0.125 J0.

N6930 G3 X-2.5921 Y-0.4609 I0.0019 J0.0124

N6935 G1 X-2.5902 Y-0.4486

N6940 X-2.5898 Y-0.4458 Z0.4503

N6945 X-2.5894 Y-0.4432 Z0.4512

N6950 X-2.5891 Y-0.4408 Z0.4527

N6955 X-2.5888 Y-0.4389 Z0.4547

N6960 X-2.5885 Y-0.4374 Z0.4571

N6965 X-2.5884 Y-0.4365 Z0.4597

N6970 Y-0.4362 Z0.4625

N6975 G0 Z1.1969

N6980 G1 X-0.55 Y-0.6075 F500.

N6985 Z1.025 F26.4

N6990 Z0.4625

N6995 G18 G2 X-0.5375 Z0.45 I0.0125 K0.

N7000 G1 X-0.525

N7005 G17 G3 X-0.5125 Y-0.595 I0. J0.0125

N7010 G2 X-0.2375 I0.1375 J0.

N7015 G1 Y-1.405

N7020 G2 X-0.5125 I-0.1375 J0.

N7025 G1 Y-0.595

N7030 G2 X-0.5059 Y-0.5854 I0.0103 J0.

N7035 G3 X-0.4986 Y-0.5763 I-0.0041 J0.0108

N7040 G2 X-0.25 Y-0.595 I0.1236 J-0.0187

N7045 G1 Y-1.405

N7050 G2 X-0.5 I-0.125 J0.

N7055 G1 Y-0.595

N7060 G2 X-0.4986 Y-0.5763 I0.125 J0.

N7065 G3 X-0.5091 Y-0.5621 I-0.0124 J0.0019

N7070 G1 X-0.5214 Y-0.5602

N7075 X-0.5242 Y-0.5598 Z0.4503

N7080 X-0.5268 Y-0.5594 Z0.4512

N7085 X-0.5292 Y-0.5591 Z0.4527

N7090 X-0.5311 Y-0.5588 Z0.4547

N7095 X-0.5326 Y-0.5585 Z0.4571

N7100 X-0.5335 Y-0.5584 Z0.4597

N7105 X-0.5338 Z0.4625

N7110 G0 Z1.5906

N7115 G1 X-1.3375 Y-2.0125 F500.

N7120 G0 Z1.1969

N7125 G1 Z1.025 F26.4

N7130 Z0.0625

N7135 G18 G2 X-1.325 Z0.05 I0.0125 K0.

N7140 G1 X-1.3125

N7145 G17 G3 X-1.3 Y-2. I0. J0.0125

N7150 G1 Y-1.625

N7155 G2 X-1.225 Y-1.55 I0.075 J0.

N7160 G1 X-0.825

N7165 Y-1.3

N7170 X-2.175

N7175 Y-1.55

N7180 X-1.775

N7185 G2 X-1.7 Y-1.625 I0. J-0.075

N7190 G1 Y-2.

N7195 G3 X-1.6875 Y-2.0125 I0.0125 J0.

N7200 G1 X-1.675

N7205 G18 G2 X-1.6625 Z0.0625 I0. K0.0125

N7210 G0 Z1.1969

N7215 X-1.325

N7220 G1 Z1.025 F26.4

N7225 Z0.0625

N7230 G2 X-1.3125 Z0.05 I0.0125 K0.

N7235 G1 X-1.3

N7240 G17 G3 X-1.2875 Y-2. I0. J0.0125

N7245 G1 Y-1.625

N7250 G2 X-1.225 Y-1.5625 I0.0625 J0.

N7255 G1 X-0.8125

N7260 Y-1.2875

N7265 X-2.1875

N7270 Y-1.5625

N7275 X-1.775

N7280 G2 X-1.7125 Y-1.625 I0. J-0.0625

N7285 G1 Y-2.

N7290 G3 X-1.7 Y-2.0125 I0.0125 J0.

N7295 G1 X-1.6875

N7300 G18 G2 X-1.675 Z0.0625 I0. K0.0125

N7305 G0 Z1.5906

(2D Contour3 3)

N7310 G17

N7315 G1 X-1.6625 Y0.0125 F500.

N7320 G0 Z1.5906

N7325 Z1.1969

N7330 G1 Z1.025 F26.4

N7335 Z-0.0269

N7340 G18 G3 X-1.675 Z-0.0394 I-0.0125 K0.

N7345 G1 X-1.6875

N7350 G17 G3 X-1.7 Y0. I0. J-0.0125

N7355 G1 Y-0.275

N7360 X-1.3

N7365 Y0.

N7370 G3 X-1.3125 Y0.0125 I-0.0125 J0.

N7375 G1 X-1.325

N7380 G18 G3 X-1.3375 Z-0.0269 I0. K0.0125

N7385 G0 Z1.1969

N7390 X-1.675

N7395 G1 Z1.025 F26.4

N7400 Z-0.0269

N7405 G3 X-1.6875 Z-0.0394 I-0.0125 K0.

N7410 G1 X-1.7

N7415 G17 G3 X-1.7125 Y0. I0. J-0.0125

N7420 G1 Y-0.2875

N7425 X-1.2875

N7430 Y0.

N7435 G3 X-1.3 Y0.0125 I-0.0125 J0.

N7440 G1 X-1.3125

N7445 G18 G3 X-1.325 Z-0.0269 I0. K0.0125

N7450 G0 Z1.5906

N7455 M9

N7460 M5

N7465 G53 G0 Z0.

(Drill1 2)

N7470 M1

N7475 T6 M6

N7480 S6000 M3

N7485 G17 G90

N7490 G54

N7495 M8

N7500 G1 X-0.375 Y-0.3 F500.

N7505 G0 G43 Z1.5906 H6

N7510 T5

N7515 G0 Z1.1969

N7520 Z0.6469

N7525 G1 Z0.4031 F60.

N7530 G0 Z0.4071

N7535 G1 Z0.3563 F60.

N7540 G0 Z0.3602

N7545 G1 Z0.3094 F60.

N7550 G0 Z0.3133

N7555 G1 Z0.2625 F60.

N7560 G0 Z0.2664

N7565 G1 Z0.2156 F60.

N7570 G0 Z0.2196

N7575 G1 Z0.1688 F60.

N7580 G0 Z0.1727

N7585 G1 Z0.1219 F60.

N7590 G0 Z0.1258

N7595 G1 Z0.075 F60.

N7600 G0 Z0.0789

N7605 G1 Z0.0281 F60.

N7610 G0 Z0.0321

N7615 G1 Z-0.0187 F60.

N7620 G0 Z1.1969

N7625 Z0.0613

N7630 G1 Z-0.0603 F60.

N7635 G0 Z1.1969

N7640 X-2.625

N7645 Z0.6469

N7650 G1 Z0.4031 F60.

N7655 G0 Z0.4071

N7660 G1 Z0.3563 F60.

N7665 G0 Z0.3602

N7670 G1 Z0.3094 F60.

N7675 G0 Z0.3133

N7680 G1 Z0.2625 F60.

N7685 G0 Z0.2664

N7690 G1 Z0.2156 F60.

N7695 G0 Z0.2196

N7700 G1 Z0.1688 F60.

N7705 G0 Z0.1727

N7710 G1 Z0.1219 F60.

N7715 G0 Z0.1258

N7720 G1 Z0.075 F60.

N7725 G0 Z0.0789

N7730 G1 Z0.0281 F60.

N7735 G0 Z0.0321

N7740 G1 Z-0.0187 F60.

N7745 G0 Z1.1969

N7750 Z0.0613

N7755 G1 Z-0.0603 F60.

N7760 G0 Z1.1969

N7765 Z1.5906

N7770 M9

N7775 M5

N7780 G53 G0 Z0.

(2D Chamfer2 2)

N7785 M1

N7790 T5 M6

N7795 S5625 M3

N7800 G17 G90

N7805 G54

N7810 M8

N7815 G1 X-2.625 Y-0.4681 F500.

N7820 G0 G43 Z1.5906 H5

N7825 T4

N7830 G0 Z1.1969

N7835 G1 Z1.0787 F10.

N7840 Z0.6794

N7845 Y-0.4931 F22.

N7850 G2 X-2.5231 Y-0.595 I0. J-0.1019 F25.

N7855 G1 Y-1.405

N7860 G2 X-2.7269 I-0.1019 J0.

N7865 G1 Y-0.595

N7870 G2 X-2.625 Y-0.4931 I0.1019 J0.

N7875 G1 Y-0.4681 F22.

N7880 G0 Z1.1969

N7885 G1 X-0.5019 Y-0.595 F500.

N7890 Z1.0787 F10.

N7895 Z0.6794

N7900 X-0.4769 F22.

N7905 G2 X-0.2731 I0.1019 J0. F25.

N7910 G1 Y-1.405

N7915 G2 X-0.4769 I-0.1019 J0.

N7920 G1 Y-0.595

N7925 X-0.5019 F22.

N7930 G0 Z1.5906

N7935 G1 X-1.2894 Y-2. F500.

N7940 G0 Z1.1969

N7945 G1 Z1.0787 F10.

N7950 Z0.3794

N7955 X-1.2644 F22.

N7960 Y-1.625 F25.

N7965 G2 X-1.225 Y-1.5856 I0.0394 J0.

N7970 G1 X-0.8125

N7975 G3 X-0.7894 Y-1.5625 I0. J0.0231

N7980 G1 Y-1.2875

N7985 G3 X-0.8125 Y-1.2644 I-0.0231 J0.

N7990 G1 X-2.1875

N7995 G3 X-2.2106 Y-1.2875 I0. J-0.0231

N8000 G1 Y-1.5625

N8005 G3 X-2.1875 Y-1.5856 I0.0231 J0.

N8010 G1 X-1.775

N8015 G2 X-1.7356 Y-1.625 I0. J-0.0394

N8020 G1 Y-2.

N8025 X-1.7106 F22.

N8030 G0 Z1.5906

(2D Chamfer2 3)

N8035 G1 X-1.8063 Y-2.0644 F500.

N8040 G0 Z1.5906

N8045 Z1.1969

N8050 G1 Z1.0787 F10.

N8055 Z0.4077

N8060 Y-2.0394 F22.

N8065 X-3. F25.

N8070 G2 X-3.0394 Y-2. I0. J0.0394

N8075 G1 Y0.

N8080 G2 X-3. Y0.0394 I0.0394 J0.

N8085 G1 X-1.775

N8090 G2 X-1.7356 Y0. I0. J-0.0394

N8095 G1 Y-0.2875

N8100 G3 X-1.7125 Y-0.3106 I0.0231 J0.

N8105 G1 X-1.2875

N8110 G3 X-1.2644 Y-0.2875 I0. J0.0231

N8115 G1 Y0.

N8120 G2 X-1.225 Y0.0394 I0.0394 J0.

N8125 G1 X0.

N8130 G2 X0.0394 Y0. I0. J-0.0394

N8135 G1 Y-2.

N8140 G2 X0. Y-2.0394 I-0.0394 J0.

N8145 G1 X-1.1938

N8150 Y-2.0644 F22.

N8155 G0 Z1.5906

N8160 M5

N8165 M9

N8170 G53 G0 Z0.

N8175 X-1.5

N8180 G53 G0 Y0.

N8185 M98 P9004

N8190 M30

%

### Product B: Lid

%

O02021 (ThPmLidB)

(Using high feed G1 F196.85 instead of G0.)

(T1 D=0.125 CR=0. - ZMIN=-0.4994 - flat end mill)

(T4 D=0.5 CR=0. - ZMIN=-0.3419 - flat end mill)

(T5 D=0.25 CR=0. TAPER=90deg - ZMIN=-0.1369 - spot drill)

N10 G90 G17

N15 G20

N20 G53 G0 Z0.

(2D Pocket1 2)

N25 T4 M6

N30 S8000 M3

N35 G17 G90

N40 G54

N45 M8

N50 G1 X-1.1051 Y-1.62 F196.85

N55 G0 G43 Z0.7881 H4

N60 T1

N65 G0 Z0.3944

N70 G1 Z0.3459 F89.4

N75 X-1.105 Y-1.6188 Z0.335

N80 X-1.1047 Y-1.6153 Z0.3247

N85 X-1.1041 Y-1.6096 Z0.3153

N90 X-1.1031 Y-1.6021 Z0.3074

N95 X-1.1016 Y-1.5931 Z0.3014

N100 G2 X-1.0995 Y-1.5831 Z0.2975 I0.2333 J-0.0444

N105 X-1.0967 Y-1.5726 Z0.2959 I0.2312 J-0.0544

N110 X-1.1015 Y-1.5928 Z0.2445 I0.2285 J-0.0649

N115 X-1.1045 Y-1.6133 Z0.1932 I0.2332 J-0.0447

N120 X-1.1058 Y-1.6339 Z0.1418 I0.2363 J-0.0242

N125 X-0.6308 Y-1.6375 Z0.1158 I0.2375 J-0.0036

N130 G1 Y-1.8566

N135 G2 X-0.6434 Y-1.8692 I-0.0126 J0.

N140 G1 X-1.0816

N145 G2 X-1.0942 Y-1.8566 I0. J0.0126

N150 G1 Y0.8566

N155 G2 X-1.0816 Y0.8692 I0.0126 J0.

N160 G1 X-0.6434

N165 G2 X-0.6308 Y0.8566 I0. J-0.0126

N170 G1 Y-1.6375

N175 Y-1.8566 Z0.1124

N180 G2 X-0.6434 Y-1.8692 Z0.1121 I-0.0126 J0.

N185 G1 X-1.0816 Z0.1052

N190 G2 X-1.0942 Y-1.8566 Z0.1049 I0. J0.0126

N195 G1 Y0.8566 Z0.0624

N200 G2 X-1.0816 Y0.8692 Z0.0621 I0.0126 J0.

N205 G1 X-0.6434 Z0.0552

N210 G2 X-0.6308 Y0.8566 Z0.0549 I0. J-0.0126

N215 G1 Y-0.4674 Z0.0342

N220 Y-1.6375

N225 Y-1.8566

N230 G2 X-0.6434 Y-1.8692 I-0.0126 J0.

N235 G1 X-1.0816

N240 G2 X-1.0942 Y-1.8566 I0. J0.0126

N245 G1 Y0.8566

N250 G2 X-1.0816 Y0.8692 I0.0126 J0.

N255 G1 X-0.6434

N260 G2 X-0.6308 Y0.8566 I0. J-0.0126

N265 G1 Y-0.4674

N270 Y-1.8566 Z0.0124

N275 G2 X-0.6434 Y-1.8692 Z0.0121 I-0.0126 J0.

N280 G1 X-1.0816 Z0.0052

N285 G2 X-1.0942 Y-1.8566 Z0.0049 I0. J0.0126

N290 G1 Y0.8566 Z-0.0376

N295 G2 X-1.0816 Y0.8692 Z-0.0379 I0.0126 J0.

N300 G1 X-0.6434 Z-0.0448

N305 G2 X-0.6308 Y0.8566 Z-0.0451 I0. J-0.0126

N310 G1 Y0.7026 Z-0.0475

N315 Y-1.8566

N320 G2 X-0.6434 Y-1.8692 I-0.0126 J0.

N325 G1 X-1.0816

N330 G2 X-1.0942 Y-1.8566 I0. J0.0126

N335 G1 Y0.8566

N340 G2 X-1.0816 Y0.8692 I0.0126 J0.

N345 G1 X-0.6434

N350 G2 X-0.6308 Y0.8566 I0. J-0.0126

N355 G1 Y0.7026

N360 G2 X-0.6323 Y0.6916 Z-0.0462 I-0.0487 J0.0012

N365 X-0.6361 Y0.6818 Z-0.0425 I-0.0472 J0.0122

N370 G1 X-0.6384 Y0.6777 Z-0.0396

N375 X-0.6412 Y0.6738 Z-0.0366

N380 X-0.6437 Y0.6708 Z-0.0326

N385 X-0.6465 Y0.668 Z-0.0287

N390 X-0.6488 Y0.666 Z-0.0239

N395 X-0.6511 Y0.6642 Z-0.0192

N400 X-0.6542 Y0.6622 Z-0.0086

N405 X-0.6553 Y0.6616 Z0.0025

N410 G0 Z0.7881

N415 G1 X-2.3801 Y-1.62 F196.85

N420 G0 Z0.3944

N425 G1 Z0.3459 F89.4

N430 X-2.38 Y-1.6188 Z0.335

N435 X-2.3797 Y-1.6153 Z0.3247

N440 X-2.3791 Y-1.6096 Z0.3153

N445 X-2.3781 Y-1.6021 Z0.3074

N450 X-2.3766 Y-1.5931 Z0.3014

N455 G2 X-2.3745 Y-1.5831 Z0.2975 I0.2333 J-0.0444

N460 X-2.3717 Y-1.5726 Z0.2959 I0.2312 J-0.0544

N465 X-2.3765 Y-1.5928 Z0.2445 I0.2285 J-0.0649

N470 X-2.3795 Y-1.6133 Z0.1932 I0.2332 J-0.0447

N475 X-2.3808 Y-1.6339 Z0.1418 I0.2363 J-0.0242

N480 X-1.9058 Y-1.6375 Z0.1158 I0.2375 J-0.0036

N485 G1 Y-1.8566

N490 G2 X-1.9184 Y-1.8692 I-0.0126 J0.

N495 G1 X-2.3566

N500 G2 X-2.3692 Y-1.8566 I0. J0.0126

N505 G1 Y0.8566

N510 G2 X-2.3566 Y0.8692 I0.0126 J0.

N515 G1 X-1.9184

N520 G2 X-1.9058 Y0.8566 I0. J-0.0126

N525 G1 Y-1.6375

N530 Y-1.8566 Z0.1124

N535 G2 X-1.9184 Y-1.8692 Z0.1121 I-0.0126 J0.

N540 G1 X-2.3566 Z0.1052

N545 G2 X-2.3692 Y-1.8566 Z0.1049 I0. J0.0126

N550 G1 Y0.8566 Z0.0624

N555 G2 X-2.3566 Y0.8692 Z0.0621 I0.0126 J0.

N560 G1 X-1.9184 Z0.0552

N565 G2 X-1.9058 Y0.8566 Z0.0549 I0. J-0.0126

N570 G1 Y-0.4674 Z0.0342

N575 Y-1.6375

N580 Y-1.8566

N585 G2 X-1.9184 Y-1.8692 I-0.0126 J0.

N590 G1 X-2.3566

N595 G2 X-2.3692 Y-1.8566 I0. J0.0126

N600 G1 Y0.8566

N605 G2 X-2.3566 Y0.8692 I0.0126 J0.

N610 G1 X-1.9184

N615 G2 X-1.9058 Y0.8566 I0. J-0.0126

N620 G1 Y-0.4674

N625 Y-1.8566 Z0.0124

N630 G2 X-1.9184 Y-1.8692 Z0.0121 I-0.0126 J0.

N635 G1 X-2.3566 Z0.0052

N640 G2 X-2.3692 Y-1.8566 Z0.0049 I0. J0.0126

N645 G1 Y0.8566 Z-0.0376

N650 G2 X-2.3566 Y0.8692 Z-0.0379 I0.0126 J0.

N655 G1 X-1.9184 Z-0.0448

N660 G2 X-1.9058 Y0.8566 Z-0.0451 I0. J-0.0126

N665 G1 Y0.7026 Z-0.0475

N670 Y-1.8566

N675 G2 X-1.9184 Y-1.8692 I-0.0126 J0.

N680 G1 X-2.3566

N685 G2 X-2.3692 Y-1.8566 I0. J0.0126

N690 G1 Y0.8566

N695 G2 X-2.3566 Y0.8692 I0.0126 J0.

N700 G1 X-1.9184

N705 G2 X-1.9058 Y0.8566 I0. J-0.0126

N710 G1 Y0.7026

N715 G2 X-1.9073 Y0.6916 Z-0.0462 I-0.0487 J0.0012

N720 X-1.9111 Y0.6818 Z-0.0425 I-0.0472 J0.0122

N725 G1 X-1.9134 Y0.6777 Z-0.0396

N730 X-1.9162 Y0.6738 Z-0.0366

N735 X-1.9187 Y0.6708 Z-0.0326

N740 X-1.9215 Y0.668 Z-0.0287

N745 X-1.9238 Y0.666 Z-0.0239

N750 X-1.9261 Y0.6642 Z-0.0192

N755 X-1.9292 Y0.6622 Z-0.0086

N760 X-1.9303 Y0.6616 Z0.0025

N765 G0 Z0.7881

N770 M9

N775 M5

N780 G53 G0 Z0.

(Bore1)

N785 M1

N790 T1 M6

N795 S6000 M3

N800 G17 G90

N805 G54

N810 M8

N815 G1 X-0.9883 Y-1.7571 F196.85

N820 G0 G43 Z0.7881 H1

N825 T4

N830 G0 Z-0.0188

N835 G1 Z-0.085 F26.4

N840 G19 G3 Y-1.7446 Z-0.0975 J0.0125 K0.

N845 G1 Y-1.7383

N850 G17 G3 X-1. Y-1.7266 I-0.0117 J0.

N855 X-0.998 Y-1.7267 Z-0.1034 I0. J-0.0234

N860 X-0.9959 Y-1.727 Z-0.1093 I-0.002 J-0.0233

N865 X-0.9939 Y-1.7274 Z-0.1152 I-0.0041 J-0.023

N870 X-0.992 Y-1.728 Z-0.1212 I-0.0061 J-0.0226

N875 X-0.9901 Y-1.7288 Z-0.1271 I-0.008 J-0.022

N880 X-0.9883 Y-1.7298 Z-0.133 I-0.0099 J-0.0212

N885 X-0.9866 Y-1.7309 Z-0.1389 I-0.0117 J-0.0202

N890 X-0.985 Y-1.7321 Z-0.1448 I-0.0134 J-0.0191

N895 X-0.9835 Y-1.7335 Z-0.1507 I-0.015 J-0.0179

N900 X-0.9821 Y-1.735 Z-0.1566 I-0.0165 J-0.0165

N905 X-0.9809 Y-1.7366 Z-0.1626 I-0.0179 J-0.015

N910 X-0.9798 Y-1.7383 Z-0.1685 I-0.0191 J-0.0134

N915 X-0.9788 Y-1.7401 Z-0.1744 I-0.0202 J-0.0117

N920 X-0.978 Y-1.742 Z-0.1803 I-0.0212 J-0.0099

N925 X-0.9774 Y-1.7439 Z-0.1862 I-0.022 J-0.008

N930 X-0.977 Y-1.7459 Z-0.1921 I-0.0226 J-0.0061

N935 X-0.9767 Y-1.748 Z-0.198 I-0.023 J-0.0041

N940 X-0.9766 Y-1.75 Z-0.204 I-0.0233 J-0.002

N945 X-0.9767 Y-1.752 Z-0.2099 I-0.0234 J0.

N950 X-0.977 Y-1.7541 Z-0.2158 I-0.0233 J0.002

N955 X-0.9774 Y-1.7561 Z-0.2217 I-0.023 J0.0041

N960 X-0.978 Y-1.758 Z-0.2276 I-0.0226 J0.0061

N965 X-0.9788 Y-1.7599 Z-0.2335 I-0.022 J0.008

N970 X-0.9798 Y-1.7617 Z-0.2394 I-0.0212 J0.0099

N975 X-0.9809 Y-1.7634 Z-0.2454 I-0.0202 J0.0117

N980 X-0.9821 Y-1.765 Z-0.2513 I-0.0191 J0.0134

N985 X-0.9835 Y-1.7665 Z-0.2572 I-0.0179 J0.015

N990 X-0.985 Y-1.7679 Z-0.2631 I-0.0165 J0.0165

N995 X-0.9866 Y-1.7691 Z-0.269 I-0.015 J0.0179

N1000 X-0.9883 Y-1.7702 Z-0.2749 I-0.0134 J0.0191

N1005 X-0.9901 Y-1.7712 Z-0.2808 I-0.0117 J0.0202

N1010 X-0.992 Y-1.772 Z-0.2868 I-0.0099 J0.0212

N1015 X-0.9939 Y-1.7726 Z-0.2927 I-0.008 J0.022

N1020 X-0.9959 Y-1.773 Z-0.2986 I-0.0061 J0.0226

N1025 X-1.0211 Y-1.74 Z-0.3025 I-0.0041 J0.023

N1030 X-0.9789 Y-1.76 I0.0211 J-0.01

N1035 X-1.0211 Y-1.74 I-0.0211 J0.01

N1040 X-1.0156 Y-1.7556 I0.0106 J-0.005

N1045 G1 X-1.0099 Y-1.7582

N1050 X-1.0074 Y-1.7594 Z-0.3022

N1055 X-1.005 Y-1.7606 Z-0.3013

N1060 X-1.0029 Y-1.7616 Z-0.2998

N1065 X-1.0011 Y-1.7624 Z-0.2978

N1070 X-0.9997 Y-1.7631 Z-0.2954

N1075 X-0.9989 Y-1.7635 Z-0.2928

N1080 X-0.9986 Y-1.7636 Z-0.29

N1085 G0 Z0.3944

N1090 G1 X-1.9883 Y-1.7571 F196.85

N1095 G0 Z-0.0188

N1100 G1 Z-0.085 F26.4

N1105 G19 G3 Y-1.7446 Z-0.0975 J0.0125 K0.

N1110 G1 Y-1.7383

N1115 G17 G3 X-2. Y-1.7266 I-0.0117 J0.

N1120 X-1.998 Y-1.7267 Z-0.1034 I0. J-0.0234

N1125 X-1.9959 Y-1.727 Z-0.1093 I-0.002 J-0.0233

N1130 X-1.9939 Y-1.7274 Z-0.1152 I-0.0041 J-0.023

N1135 X-1.992 Y-1.728 Z-0.1212 I-0.0061 J-0.0226

N1140 X-1.9901 Y-1.7288 Z-0.1271 I-0.008 J-0.022

N1145 X-1.9883 Y-1.7298 Z-0.133 I-0.0099 J-0.0212

N1150 X-1.9866 Y-1.7309 Z-0.1389 I-0.0117 J-0.0202

N1155 X-1.985 Y-1.7321 Z-0.1448 I-0.0134 J-0.0191

N1160 X-1.9835 Y-1.7335 Z-0.1507 I-0.015 J-0.0179

N1165 X-1.9821 Y-1.735 Z-0.1566 I-0.0165 J-0.0165

N1170 X-1.9809 Y-1.7366 Z-0.1626 I-0.0179 J-0.015

N1175 X-1.9798 Y-1.7383 Z-0.1685 I-0.0191 J-0.0134

N1180 X-1.9788 Y-1.7401 Z-0.1744 I-0.0202 J-0.0117

N1185 X-1.978 Y-1.742 Z-0.1803 I-0.0212 J-0.0099

N1190 X-1.9774 Y-1.7439 Z-0.1862 I-0.022 J-0.008

N1195 X-1.977 Y-1.7459 Z-0.1921 I-0.0226 J-0.0061

N1200 X-1.9767 Y-1.748 Z-0.198 I-0.023 J-0.0041

N1205 X-1.9766 Y-1.75 Z-0.204 I-0.0233 J-0.002

N1210 X-1.9767 Y-1.752 Z-0.2099 I-0.0234 J0.

N1215 X-1.977 Y-1.7541 Z-0.2158 I-0.0233 J0.002

N1220 X-1.9774 Y-1.7561 Z-0.2217 I-0.023 J0.0041

N1225 X-1.978 Y-1.758 Z-0.2276 I-0.0226 J0.0061

N1230 X-1.9788 Y-1.7599 Z-0.2335 I-0.022 J0.008

N1235 X-1.9798 Y-1.7617 Z-0.2394 I-0.0212 J0.0099

N1240 X-1.9809 Y-1.7634 Z-0.2454 I-0.0202 J0.0117

N1245 X-1.9821 Y-1.765 Z-0.2513 I-0.0191 J0.0134

N1250 X-1.9835 Y-1.7665 Z-0.2572 I-0.0179 J0.015

N1255 X-1.985 Y-1.7679 Z-0.2631 I-0.0165 J0.0165

N1260 X-1.9866 Y-1.7691 Z-0.269 I-0.015 J0.0179

N1265 X-1.9883 Y-1.7702 Z-0.2749 I-0.0134 J0.0191

N1270 X-1.9901 Y-1.7712 Z-0.2808 I-0.0117 J0.0202

N1275 X-1.992 Y-1.772 Z-0.2868 I-0.0099 J0.0212

N1280 X-1.9939 Y-1.7726 Z-0.2927 I-0.008 J0.022

N1285 X-1.9959 Y-1.773 Z-0.2986 I-0.0061 J0.0226

N1290 X-2.0211 Y-1.74 Z-0.3025 I-0.0041 J0.023

N1295 X-1.9789 Y-1.76 I0.0211 J-0.01

N1300 X-2.0211 Y-1.74 I-0.0211 J0.01

N1305 X-2.0156 Y-1.7556 I0.0106 J-0.005

N1310 G1 X-2.0099 Y-1.7582

N1315 X-2.0074 Y-1.7594 Z-0.3022

N1320 X-2.005 Y-1.7606 Z-0.3013

N1325 X-2.0029 Y-1.7616 Z-0.2998

N1330 X-2.0011 Y-1.7624 Z-0.2978

N1335 X-1.9997 Y-1.7631 Z-0.2954

N1340 X-1.9989 Y-1.7635 Z-0.2928

N1345 X-1.9986 Y-1.7636 Z-0.29

N1350 G0 Z0.7881

(2D Contour2)

N1355 G1 X-1.0063 Y-1.7625 F196.85

N1360 G0 Z0.7881

N1365 Z0.3944

N1370 G1 Z0.2225 F26.4

N1375 Z-0.3097

N1380 G18 G2 X-0.9938 Z-0.3222 I0.0125 K0. F8.976

N1385 G1 X-0.9813

N1390 G17 G3 X-0.9688 Y-1.75 I0. J0.0125

N1395 X-1. Y-1.7188 I-0.0312 J0.

N1400 Y-1.7813 I0. J-0.0313

N1405 X-0.9688 Y-1.75 I0. J0.0313

N1410 X-0.9813 Y-1.7375 I-0.0125 J0.

N1415 G1 X-0.9938

N1420 G18 G3 X-1.0063 Z-0.3097 I0. K0.0125

N1425 G0 Z0.3944

N1430 G1 X-2.0063 Y-1.7625 F196.85

N1435 Z0.2225 F26.4

N1440 Z-0.3097

N1445 G2 X-1.9938 Z-0.3222 I0.0125 K0. F8.976

N1450 G1 X-1.9813

N1455 G17 G3 X-1.9688 Y-1.75 I0. J0.0125

N1460 X-2. Y-1.7188 I-0.0312 J0.

N1465 Y-1.7813 I0. J-0.0313

N1470 X-1.9688 Y-1.75 I0. J0.0313

N1475 X-1.9813 Y-1.7375 I-0.0125 J0.

N1480 G1 X-1.9938

N1485 G18 G3 X-2.0063 Z-0.3097 I0. K0.0125

N1490 G0 Z0.7881

(2D Pocket4 2)

N1495 G17

N1500 G1 X-1.9969 Y-0.9075 F196.85

N1505 G0 Z0.7881

N1510 Z0.169

N1515 G1 Z-0.0028 F26.4

N1520 Z-0.0498

N1525 X-1.9963

N1530 X-1.9575

N1535 Y-0.0925

N1540 X-1.9961

N1545 X-1.9575 Z-0.0507

N1550 Y-0.9075 Z-0.0708

N1555 X-1.9963 Z-0.0717

N1560 X-1.9575

N1565 Y-0.0925

N1570 X-1.9961

N1575 X-1.9575 Z-0.0727

N1580 Y-0.9075 Z-0.0927

N1585 X-1.9963 Z-0.0937

N1590 X-1.9575

N1595 Y-0.0925

N1600 X-1.9961

N1605 X-1.9575 Z-0.0946

N1610 Y-0.9075 Z-0.1146

N1615 X-1.9963 Z-0.1156

N1620 X-1.9575

N1625 Y-0.0925

N1630 X-1.9961

N1635 X-1.9575 Z-0.1165

N1640 Y-0.9075 Z-0.1366

N1645 X-1.9963 Z-0.1375

N1650 X-1.9575

N1655 Y-0.0925

N1660 X-1.9961

N1665 X-1.9575 Z-0.1385

N1670 Y-0.9075 Z-0.1585

N1675 X-1.9963 Z-0.1595

N1680 X-1.9575

N1685 Y-0.0925

N1690 X-1.9961

N1695 X-1.9575 Z-0.1604

N1700 Y-0.9075 Z-0.1805

N1705 X-1.9963 Z-0.1814

N1710 X-1.9575

N1715 Y-0.0925

N1720 X-1.9961

N1725 G0 Z0.7881

N1730 X-1.0031

N1735 Z0.169

N1740 G1 Z-0.0028 F26.4

N1745 Z-0.0498

N1750 X-1.0037

N1755 X-1.0425

N1760 Y-0.9075

N1765 X-1.0039

N1770 X-1.0425 Z-0.0507

N1775 Y-0.0925 Z-0.0708

N1780 X-1.0037 Z-0.0717

N1785 X-1.0425

N1790 Y-0.9075

N1795 X-1.0039

N1800 X-1.0425 Z-0.0727

N1805 Y-0.0925 Z-0.0927

N1810 X-1.0037 Z-0.0937

N1815 X-1.0425

N1820 Y-0.9075

N1825 X-1.0039

N1830 X-1.0425 Z-0.0946

N1835 Y-0.0925 Z-0.1146

N1840 X-1.0037 Z-0.1156

N1845 X-1.0425

N1850 Y-0.9075

N1855 X-1.0039

N1860 X-1.0425 Z-0.1165

N1865 Y-0.0925 Z-0.1366

N1870 X-1.0037 Z-0.1375

N1875 X-1.0425

N1880 Y-0.9075

N1885 X-1.0039

N1890 X-1.0425 Z-0.1385

N1895 Y-0.0925 Z-0.1585

N1900 X-1.0037 Z-0.1595

N1905 X-1.0425

N1910 Y-0.9075

N1915 X-1.0039

N1920 X-1.0425 Z-0.1604

N1925 Y-0.0925 Z-0.1805

N1930 X-1.0037 Z-0.1814

N1935 X-1.0425

N1940 Y-0.9075

N1945 X-1.0039

N1950 G0 Z0.7881

(2D Pocket4 3)

N1955 G1 X-2.0025 Y-0.5785 F196.85

N1960 G0 Z0.7881

N1965 Z0.169

N1970 G1 Z0.0831 F26.4

N1975 G19 G2 Y-0.5906 Z0.0706 J-0.0125 K0.

N1980 G1 Y-0.9075 Z0.0595

N1985 X-1.9975 Z0.0594

N1990 Y-0.0925 Z0.0309

N1995 X-2.0025 Z0.0307

N2000 Y-0.9075 Z0.0023

N2005 X-1.9975 Z0.0021

N2010 Y-0.0925 Z-0.0264

N2015 X-2.0025 Z-0.0265

N2020 Y-0.9075 Z-0.055

N2025 X-1.9975 Z-0.0552

N2030 Y-0.0925 Z-0.0836

N2035 X-2.0025 Z-0.0838

N2040 Y-0.9075 Z-0.1123

N2045 X-1.9975 Z-0.1124

N2050 Y-0.0925 Z-0.1409

N2055 X-2.0025 Z-0.1411

N2060 Y-0.9075 Z-0.1695

N2065 X-1.9975 Z-0.1697

N2070 Y-0.0925 Z-0.1982

N2075 X-2.0025 Z-0.1983

N2080 Y-0.9075 Z-0.2268

N2085 X-1.9975 Z-0.227

N2090 Y-0.0925 Z-0.2554

N2095 X-2.0025 Z-0.2556

N2100 Y-0.9075 Z-0.2841

N2105 X-1.9975 Z-0.2843

N2110 Y-0.0925 Z-0.3127

N2115 X-2.0025 Z-0.3129

N2120 Y-0.9075 Z-0.3413

N2125 X-1.9975 Z-0.3415

N2130 Y-0.8975 Z-0.3419

N2135 Y-0.1175 F8.976

N2140 Y-0.0925 F2.244

N2145 X-2.0025

N2150 Y-0.8825 F8.976

N2155 Y-0.9075 F2.244

N2160 X-1.9975

N2165 Y-0.8975 F8.976

N2170 X-1.9976 Y-0.8965 Z-0.3418

N2175 X-1.9979 Y-0.8956 Z-0.3414

N2180 X-1.9984 Y-0.8948 Z-0.3409

N2185 X-1.9988 Y-0.8943 Z-0.3401

N2190 X-1.9992 Y-0.8939 Z-0.3393

N2195 X-1.9995 Y-0.8937 Z-0.3383

N2200 X-1.9996 Y-0.8936 Z-0.3373

N2205 G0 Z0.3944

N2210 G1 X-0.9975 Y-0.4265 F196.85

N2215 G0 Z0.169

N2220 G1 Z0.0831 F26.4

N2225 G3 Y-0.4144 Z0.0706 J0.0125 K0.

N2230 G1 Y-0.0925 Z0.0594

N2235 X-1.0025 Z0.0592

N2240 Y-0.9075 Z0.0307

N2245 X-0.9975 Z0.0306

N2250 Y-0.0925 Z0.0021

N2255 X-1.0025 Z0.0019

N2260 Y-0.9075 Z-0.0265

N2265 X-0.9975 Z-0.0267

N2270 Y-0.0925 Z-0.0552

N2275 X-1.0025 Z-0.0553

N2280 Y-0.9075 Z-0.0838

N2285 X-0.9975 Z-0.084

N2290 Y-0.0925 Z-0.1124

N2295 X-1.0025 Z-0.1126

N2300 Y-0.9075 Z-0.1411

N2305 X-0.9975 Z-0.1413

N2310 Y-0.0925 Z-0.1697

N2315 X-1.0025 Z-0.1699

N2320 Y-0.9075 Z-0.1983

N2325 X-0.9975 Z-0.1985

N2330 Y-0.0925 Z-0.227

N2335 X-1.0025 Z-0.2272

N2340 Y-0.9075 Z-0.2556

N2345 X-0.9975 Z-0.2558

N2350 Y-0.0925 Z-0.2843

N2355 X-1.0025 Z-0.2844

N2360 Y-0.9075 Z-0.3129

N2365 X-0.9975 Z-0.3131

N2370 Y-0.0925 Z-0.3415

N2375 X-1.0025 Z-0.3417

N2380 Y-0.0975 Z-0.3419

N2385 Y-0.8825 F8.976

N2390 Y-0.9075 F2.244

N2395 X-0.9975

N2400 Y-0.1175 F8.976

N2405 Y-0.0953 F2.244

N2410 Y-0.0925

N2415 X-1.0025

N2420 Y-0.0975 F8.976

N2425 X-1.0024 Y-0.0985 Z-0.3418

N2430 X-1.0021 Y-0.0994 Z-0.3414

N2435 X-1.0016 Y-0.1002 Z-0.3409

N2440 X-1.0012 Y-0.1007 Z-0.3401

N2445 X-1.0008 Y-0.1011 Z-0.3393

N2450 X-1.0005 Y-0.1013 Z-0.3383

N2455 X-1.0004 Y-0.1014 Z-0.3373

N2460 G0 Z0.7881

N2465 M9

N2470 M5

N2475 G53 G0 Z0.

(2D Pocket3 2)

N2480 M1

N2485 T4 M6

N2490 S6000 M3

N2495 G17 G90

N2500 G54

N2505 M8

N2510 G1 X-1.5009 Y-1.7856 F196.85

N2515 G0 G43 Z0.7881 H4

N2520 T1

N2525 G0 Z0.3944

N2530 G1 Z-0.1563 F89.4

N2535 X-1.5008 Y-1.7854 Z-0.1588

N2540 X-1.5007 Y-1.7845 Z-0.1611

N2545 X-1.5005 Y-1.7832 Z-0.1633

N2550 X-1.5002 Y-1.7815 Z-0.165

N2555 X-1.4999 Y-1.7794 Z-0.1664

N2560 X-1.4995 Y-1.777 Z-0.1672

N2565 X-1.4991 Y-1.7745 Z-0.1675

N2570 X-1.4948 Y-1.7475

N2575 X-1.4947 Y-1.7459

N2580 Y0.416

N2585 G3 X-1.5053 I-0.0053 J0.

N2590 G1 Y0.4159

N2595 Y-1.746

N2600 X-1.5051 Y-1.748 Z-0.1671

N2605 X-1.5046 Y-1.7499 Z-0.1667

N2610 X-1.5038 Y-1.7514 Z-0.1656

N2615 X-1.5028 Y-1.7527 Z-0.1645

N2620 X-1.5012 Y-1.7543 Z-0.1611

N2625 X-1.5006 Y-1.7547 Z-0.1571

N2630 G0 Z0.7881

(2D Pocket3 3)

N2635 G1 X-1.4991 Y1.2852 F196.85

N2640 G0 Z0.7881

N2645 Z0.3944

N2650 G1 Z-0.3306 F89.4

N2655 X-1.4992 Y1.2849 Z-0.3331

N2660 X-1.4993 Y1.2841 Z-0.3355

N2665 X-1.4995 Y1.2828 Z-0.3376

N2670 X-1.4998 Y1.281 Z-0.3394

N2675 X-1.5001 Y1.2789 Z-0.3408

N2680 X-1.5005 Y1.2766 Z-0.3416

N2685 X-1.5009 Y1.2741 Z-0.3419

N2690 X-1.5052 Y1.247

N2695 X-1.5053 Y1.2454

N2700 Y0.4397

N2705 X-1.4947

N2710 Y1.

N2715 Y1.2458

N2720 X-1.4949 Y1.2478 Z-0.3415

N2725 X-1.4954 Y1.2497 Z-0.3411

N2730 X-1.4962 Y1.2512 Z-0.34

N2735 X-1.4972 Y1.2526 Z-0.3388

N2740 X-1.4988 Y1.2541 Z-0.3355

N2745 X-1.4994 Y1.2545 Z-0.3315

N2750 G0 Z0.3944

N2755 G1 X-1.5009 Y-2.2855 F196.85

N2760 Z-0.3306 F89.4

N2765 Y-2.2852 Z-0.3331

N2770 X-1.5007 Y-2.2844 Z-0.3355

N2775 X-1.5005 Y-2.2831 Z-0.3376

N2780 X-1.5002 Y-2.2813 Z-0.3394

N2785 X-1.4999 Y-2.2792 Z-0.3408

N2790 X-1.4995 Y-2.2769 Z-0.3416

N2795 X-1.4991 Y-2.2744 Z-0.3419

N2800 X-1.4948 Y-2.247

N2805 X-1.4947 Y-2.2454

N2810 Y-2.

N2815 Y-1.7697

N2820 X-1.5053

N2825 Y-2.2458

N2830 X-1.5051 Y-2.2478 Z-0.3415

N2835 X-1.5046 Y-2.2497 Z-0.3411

N2840 X-1.5038 Y-2.2512 Z-0.34

N2845 X-1.5028 Y-2.2526 Z-0.3388

N2850 X-1.5012 Y-2.2541 Z-0.3355

N2855 X-1.5006 Y-2.2545 Z-0.3315

N2860 G0 Z0.7881

N2865 M9

N2870 M5

N2875 G53 G0 Z0.

(2D Contour3)

N2880 M1

N2885 T1 M6

N2890 S6000 M3

N2895 G17 G90

N2900 G54

N2905 M8

N2910 G1 X-1.325 Y-1.6425 F196.85

N2915 G0 G43 Z0.7881 H1

N2920 T5

N2925 G0 Z0.3944

N2930 G1 Z0.2225 F26.4

N2935 Z-0.155

N2940 G18 G2 X-1.3125 Z-0.1675 I0.0125 K0. F8.976

N2945 G1 X-1.3

N2950 G17 G3 X-1.2875 Y-1.63 I0. J0.0125

N2955 G1 Y0.3

N2960 G3 X-1.3 Y0.3125 I-0.0125 J0.

N2965 G1 X-1.3125

N2970 G18 G3 X-1.325 Z-0.155 I0. K0.0125

N2975 G0 Z0.3944

N2980 X-1.675

N2985 G1 Z0.2225 F26.4

N2990 Z-0.155

N2995 G3 X-1.6875 Z-0.1675 I-0.0125 K0. F8.976

N3000 G1 X-1.7

N3005 G17 G3 X-1.7125 Y0.3 I0. J-0.0125

N3010 G1 Y-1.63

N3015 G3 X-1.7 Y-1.6425 I0.0125 J0.

N3020 G1 X-1.6875

N3025 G18 G2 X-1.675 Z-0.155 I0. K0.0125

N3030 G0 Z0.7881

(2D Contour3 2)

N3035 G17

N3040 G1 X-1.325 Y-2.0125 F196.85

N3045 G0 Z0.7881

N3050 Z0.3944

N3055 G1 Z0.2225 F26.4

N3060 Z-0.4869

N3065 G18 G2 X-1.3125 Z-0.4994 I0.0125 K0. F8.976

N3070 G1 X-1.3

N3075 G17 G3 X-1.2875 Y-2. I0. J0.0125

N3080 G1 Y-1.63

N3085 G3 X-1.355 Y-1.5625 I-0.0675 J0.

N3090 G1 X-1.645

N3095 G3 X-1.7125 Y-1.63 I0. J-0.0675

N3100 G1 Y-2.

N3105 G3 X-1.7 Y-2.0125 I0.0125 J0.

N3110 G1 X-1.6875

N3115 G18 G2 X-1.675 Z-0.4869 I0. K0.0125

N3120 G0 Z0.3944

N3125 Y1.0125

N3130 G1 Z0.2225 F26.4

N3135 Z-0.4869

N3140 G3 X-1.6875 Z-0.4994 I-0.0125 K0. F8.976

N3145 G1 X-1.7

N3150 G17 G3 X-1.7125 Y1. I0. J-0.0125

N3155 G1 Y0.3

N3160 G3 X-1.645 Y0.2325 I0.0675 J0.

N3165 G1 X-1.355

N3170 G3 X-1.2875 Y0.3 I0. J0.0675

N3175 G1 Y1.

N3180 G3 X-1.3 Y1.0125 I-0.0125 J0.

N3185 G1 X-1.3125

N3190 G18 G3 X-1.325 Z-0.4869 I0. K0.0125

N3195 G0 Z0.7881

N3200 M9

N3205 M5

N3210 G53 G0 Z0.

(2D Chamfer1)

N3215 M1

N3220 T5 M6

N3225 S4500 M3

N3230 G17 G90

N3235 G54

N3240 M8

N3245 G1 X-0.9706 Y-1.75 F196.85

N3250 G0 G43 Z0.7881 H5

N3255 T4

N3260 G0 Z0.3944

N3265 G1 Z0.2762 F10.

N3270 Z-0.1369

N3275 X-0.9456 F22.

N3280 G3 X-1. Y-1.6956 I-0.0544 J0. F25.

N3285 Y-1.8044 I0. J-0.0544

N3290 X-0.9456 Y-1.75 I0. J0.0544

N3295 G1 X-0.9706 F22.

N3300 G0 Z0.3944

N3305 X-1.9706

N3310 G1 Z0.2762 F10.

N3315 Z-0.1369

N3320 X-1.9456 F22.

N3325 G3 X-2. Y-1.6956 I-0.0544 J0. F25.

N3330 Y-1.8044 I0. J-0.0544

N3335 X-1.9456 Y-1.75 I0. J0.0544

N3340 G1 X-1.9706 F22.

N3345 G0 Z0.7881

N3350 M5

N3355 M9

N3360 G53 G0 Z0.

N3365 X-1.5

N3370 G53 G0 Y0.

N3375 M98 P9004

N3380 M30

%
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

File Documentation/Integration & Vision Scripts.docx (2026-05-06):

# Computer Vision and Integration: Vision Overview


ME500: Advanced Manufacturing

Spring 2026

Variable Product Manufacturing (Thursday PM Lab Group)

Chris Daub, Riley Hubscher, Mukhamed Kerimkul, Bramasto Prasojo, and Chaitanya Sai Nikith Rambha

Table of Contents

Overview 2

Process Diagram 3

Setup 4

Codebase 4

Integration Scripts 4

listener_server.py 4

modbus_server.py 5

Vision.py 6

Overview 6

Camera 6

Crop 7

Process 8

Identify 8

vision_test.py 8

Misc. Scripts 9

vision_utils.py 9

vision_extras.py 9

Supporting Elements 10

Camera Mount 10

Tray Pegs 10

Conclusion 11

# Overview

This document contains a high level flow chart for the vision system functionality and a description for each of the files highlighting key operations. All python files can be found in the attached zip folder.

The general function of the system is to scan the lid of the swivel hook product to determine if the lid is of the tall or short type. This process is started by Rosie and later communicated back to Rosie. Upon completion, Rosie is able to correctly identify which assembly procedure to perform.

This project relies heavily on OpenCV, the “world’s largest computer vision library” as per their website. More information can be found here: OpenCV - Open Computer Vision Library (https://opencv.org/)

### Process Diagram

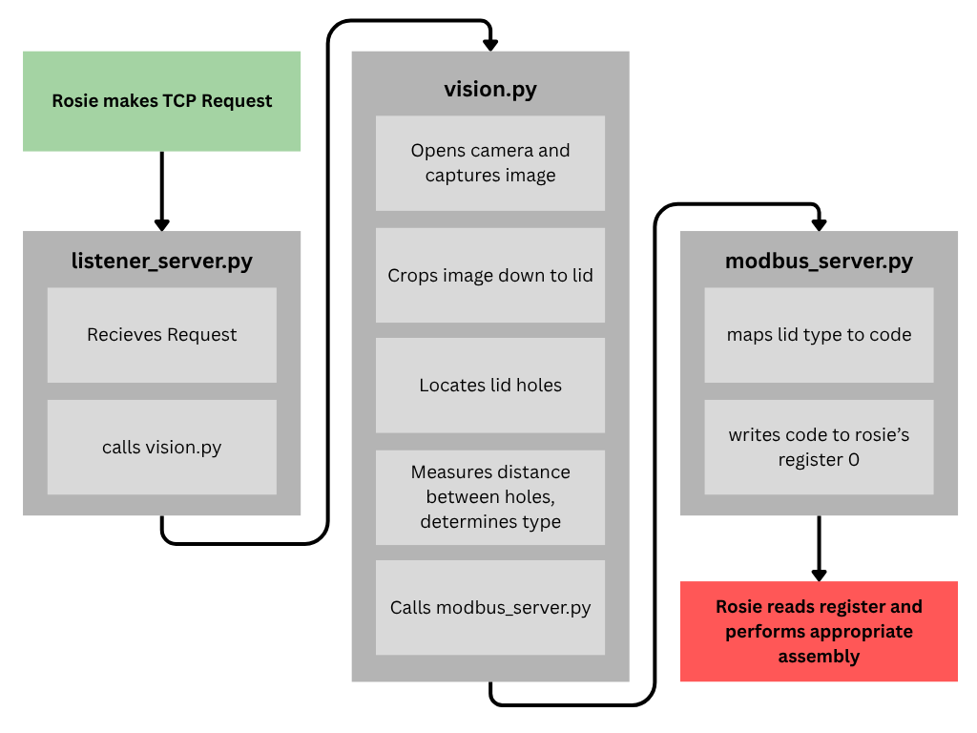
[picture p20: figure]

Fig. 1 - General Code Flowchart

The flow diagram above shows the key functionality from call to post of the vision system. An important note: both listener_server.py and modbus_server.py must be started in individual terminals before running BUMES. Test and utility files are not shown.

### Setup

The vision system is run on the computer at station 1 and requires python 3.14.3. Setting up a virtual environment in VS Code is crucial to not breaking the existing code for the ink making lab and system. The following code must be run in order to retrieve all dependencies.

>> pip install -r requirements.txt

From here, the following code must be run in separate terminals to start up the vision system.

>> python listener_server.py

>> python modbus_server.py

At this point, you should have a working computer vision block for the FMC. The rest of this document will cover functionality of the code base.

# Codebase

## Integration Scripts

All text in bold is a function, all text in bold italics is a script

### listener_server.py

listener_server.py is responsible for handling incoming requests from Rosie. The print statements in listener_server.py verify the server started successfully and that communications are properly carried out.

The following variables designate host and port for the server and must match Rosie’s settings.

HOST = "10.241.34.37"

PORT = 30002

listener_server_test.py runs a local server and verifies connections can be handled. This test can be run with the following command.

>> python listener_server_test.py

### modbus_server.py

modbus_server.py acts like a “message board”, allowing the vision system to post to Rosie, setting a registry such that Rosie has access to the results of vision.py. Almost all of the code is setup for the server.

The following variables designate host, client, and port for modbus server.

HOST = '0.0.0.0'

CLIENT = "127.0.0.1"

PORT = 502

REGISTER_ADDRESS = 0

There is a short snippet of code at the bottom that can be uncommented as a test.

>> python listener_server_test.py

## Vision.py

### Overview

vision.py is responsible for connecting to the camera, the capture of an image, and the computer vision algorithm that determines the lid type. The computer vision algorithm consists of 3 major steps: crop, process, and identify. The algorithm is encapsulated in lidTypeIndicator

### Camera

The camera is handled by the scan function. scan connects to the camera, buffers 30 frames and captures an image. This is attempted 3 times to ensure a success.

The following argument defines which camera input to use and may need adjustment.

cv2.VideoCapture(cv2.CAP_DSHOW)

During early development, scan was forced to return a preloaded image for local testing.

scan captured the following image which will be used for the rest of the documentation.

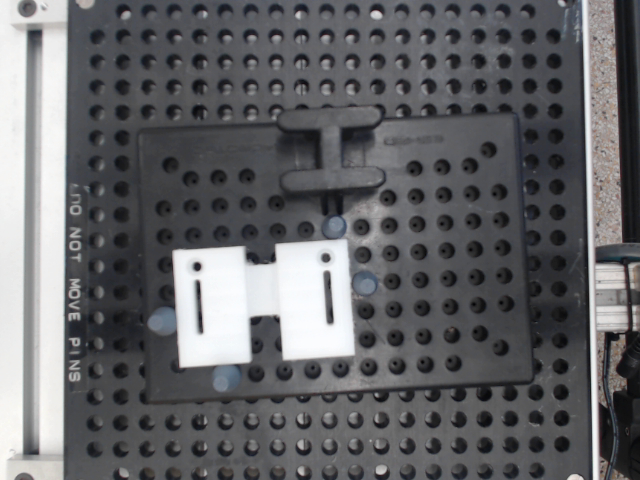
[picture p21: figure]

Fig. 2 - Test Image

### Crop

The crop step begins by calling clipBlacks which sets all pixels less than 200 (nearly white) to black

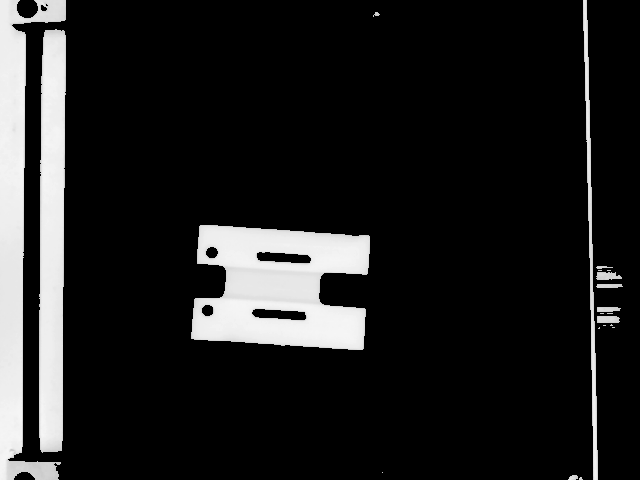
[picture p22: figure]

Fig. 3 - clipBlacks() Result

The resulting image is then passed to findLargestConnected This function finds all contiguous white areas and returns a “stats” object. crop is then passed the clipped image and the stats and crops the image down to the lid.

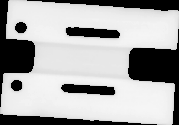
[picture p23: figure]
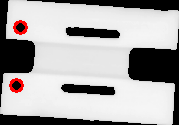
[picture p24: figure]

Fig. 4 - crop Result | Fig. 5 - findHoles Result

### Process

The process step is handled by findHoles. This applies an open CV blob detector to find the locations of holes based on various parameters like circularity, area, etc. These were fine tuned for the lid’s holes, primarily to filter out larger and smaller holes. Documentation can be found here: https://docs.opencv.org/4.x/d0/d7a/classcv_1_1SimpleBlobDetector.html. See Fig. 6 for results. All found holes are then passed to calcHoleSpacing which measures the distance between all pairs of holes. In our case that is only 2. Previous lid types required this more sophisticated approach.

### Identify

The resulting hole distance is passed to lidTypeByHoles. This function takes the shortest distance between each of the hole pairs and compares them to a threshold value, in our case 85. This number was arrived at after running calcHoleSpacing on over 600 images, taking the average for both lid types and finding the midpoint, 85, which acts as a threshold. For the short lids, distances were ~110 and for the tall lids, distances were ~60, with each having a variance of ~.15. This produces a confidence interval of ±0.044 for each lid type. The threshold of 85 sits nearly 11 standard deviations away from either distribution's mean. By common quality standards, the algorithm is always right.

### vision_test.py

vision_test.py was absolutely critical in producing a reliable algorithm. Functionality is for setting up tests and running them. Tests are run on vision.lidTypeIndicator, providing a holistic test of the vision algorithm. Key functionality includes

- bulkImagePath which creates a path for saving and retrieving images,
- testMessageHandler which provides consistent test messaging,
- individualTest which allows testing of individual images
- bulkTest which runs bulk testing
- bulkSave which captures a given number of images from the camera.

bulkSave was run 4 times during different times of the day, each capturing 200 images of each lid.

## Misc. Scripts

### vision_utils.py

This file holds utilities used across various parts of the system. One particularly useful addition RESULT_CODES allows the entire system to have one source of truth as well as quick changes if necessary, and even additions for any future expansions.

RESULT_CODES = ["unknown","tall","short",]

Other utilities include crop, saveImage, and loadImage.

Two functions displayWindow and drawStuffShowStuff are absolutely crucial in debugging, allowing the user to see the image during any step of processing.

### vision_extras.py

This file acts as a collection of open CV functions not used. These provide a good jumping off point for anyone interested in expanding the functionality of this project or their own.

# Supporting Elements

### Camera Mount

A web cam mount was created using 8020 on the existing camera frame at station 1. This mount is adjustable vertically and proved to be reliable across 2 teams projects.

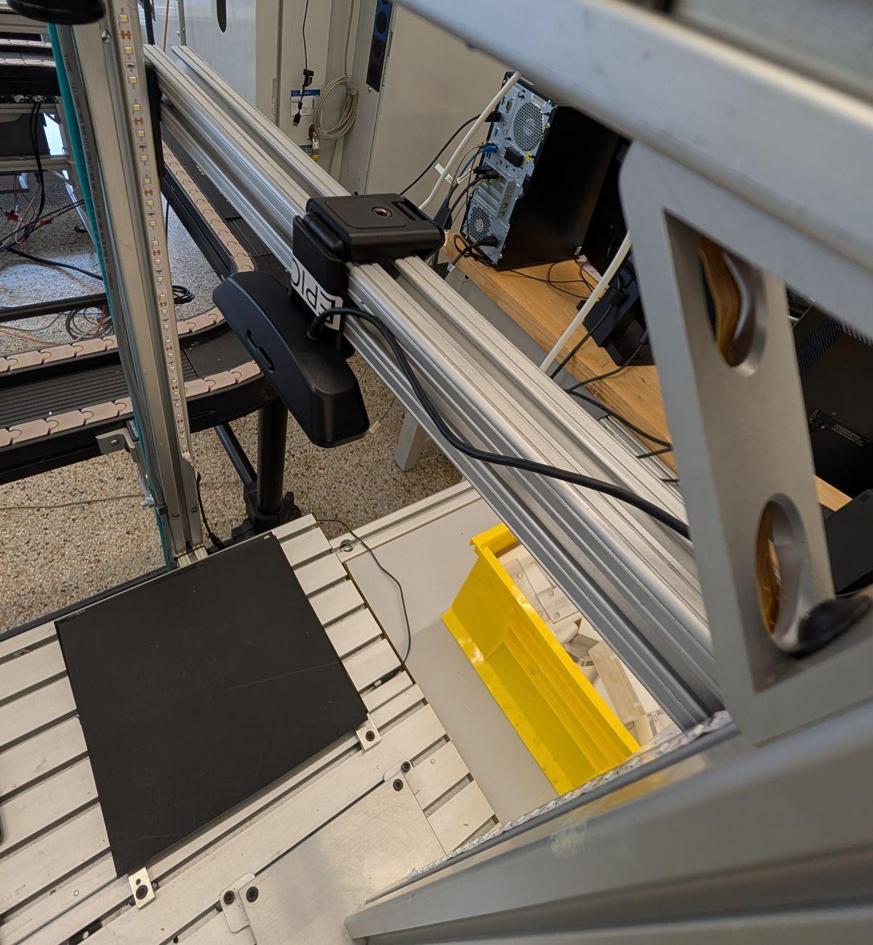
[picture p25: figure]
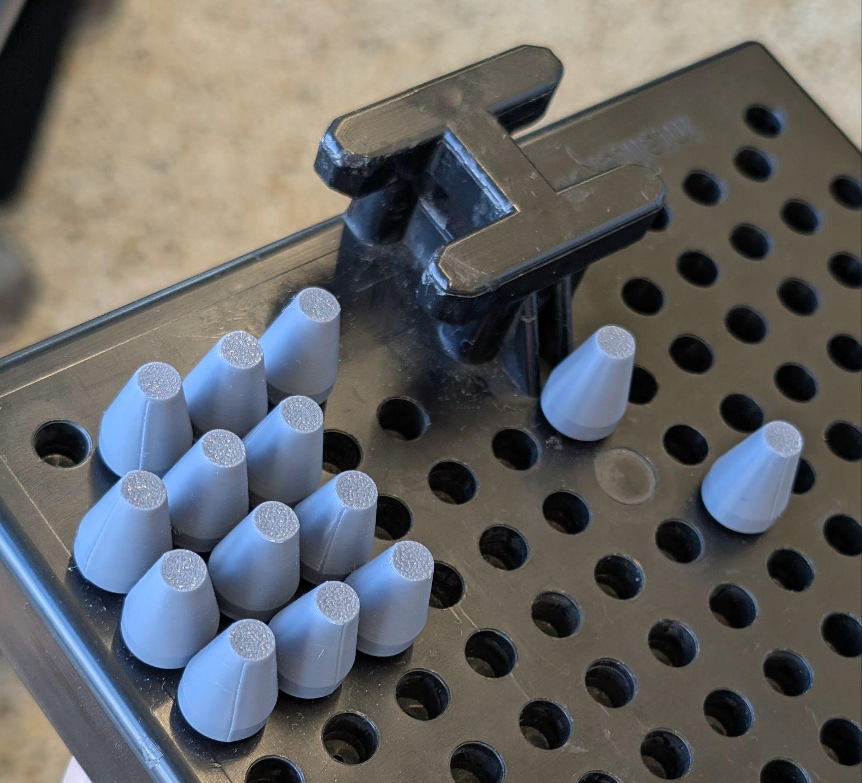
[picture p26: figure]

Fig. 5 - Camera Mount | Fig. 6 - Tray Pegs

### Tray Pegs

The existing metal tray pegs produced white pixels in the captured image adding unnecessary complexity. The pegs were modeled in CAD and 3d printed, acting just as well while simplifying the computer vision algorithm.

# Conclusion

At the conclusion of this project, the system demonstrated strong stability and accuracy throughout testing. Both servers operated without failure, and the computer vision algorithm consistently produced correct results. While the algorithm itself is relatively straightforward, its reliability highlights how thoughtful design decisions can significantly improve both system performance and overall quality.

Initially, the plan included developing and benchmarking multiple algorithms — testing each independently and exploring whether ensemble approaches might yield better accuracy. Due to time constraints, this was not pursued, though it remains a worthwhile direction for future work. I had also hoped to implement conditional behaviour off the unknown category, providing a toy example of quality control.

The system as delivered provides a robust and well-structured foundation for further development. The core components — listener_server.py, modbus_server.py, vision_utils.py and vision_test.py — are each designed to work with this implementation of vision.py but there wete built with extensibility in mind, accelerating any future implementations of vision.py. Potential directions include implementing more complex conditional logic, create a quality control system, or adapting the entry point to drive conditional behaviour earlier in the ADML.

ME500: Advanced Manufacturing Daub, Hubscher, Kerimkul, Prasojo, and Rambha

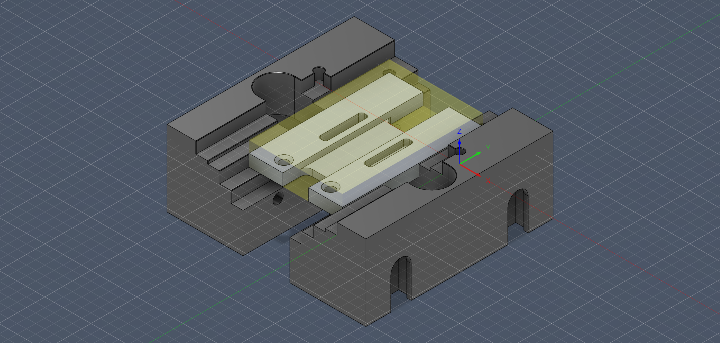
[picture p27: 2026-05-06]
CAD:CAM Files/Lid1VCNC_1.png

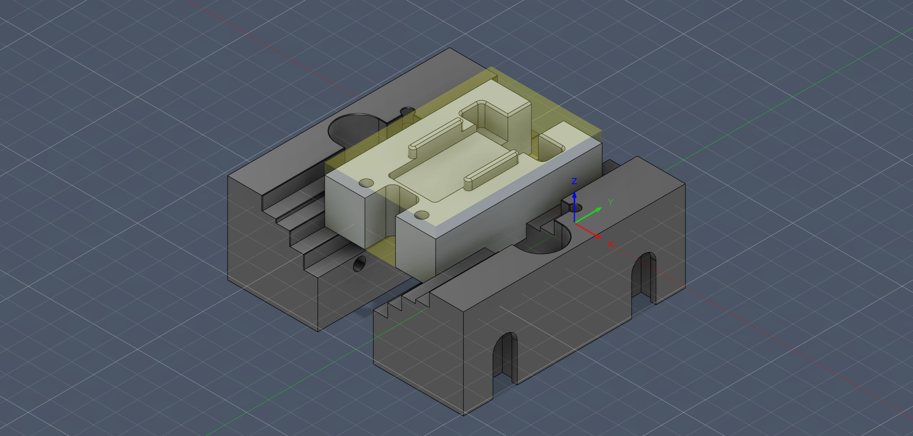
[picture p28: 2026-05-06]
CAD:CAM Files/Base1VCNC_1.png

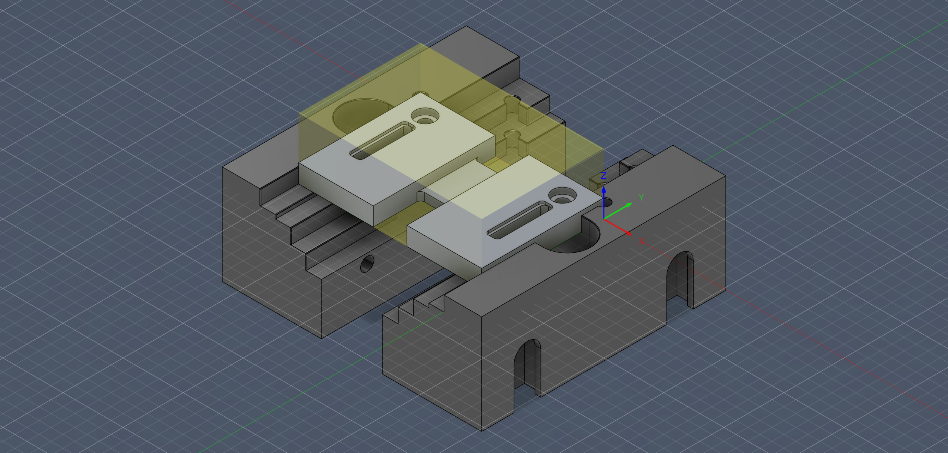
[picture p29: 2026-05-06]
CAD:CAM Files/Lid1CNC_1.png

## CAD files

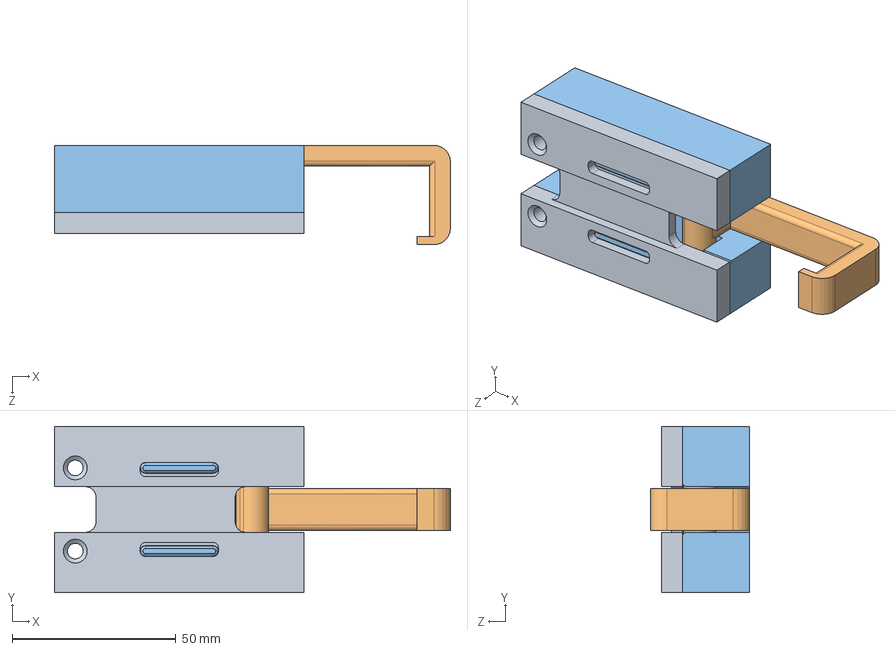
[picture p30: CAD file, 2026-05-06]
CAD:CAM Files/AssemblyB2.SLDASM
120.9 x 50.8 x 30.4 mm
Base1V
Hook1V
Lid1V

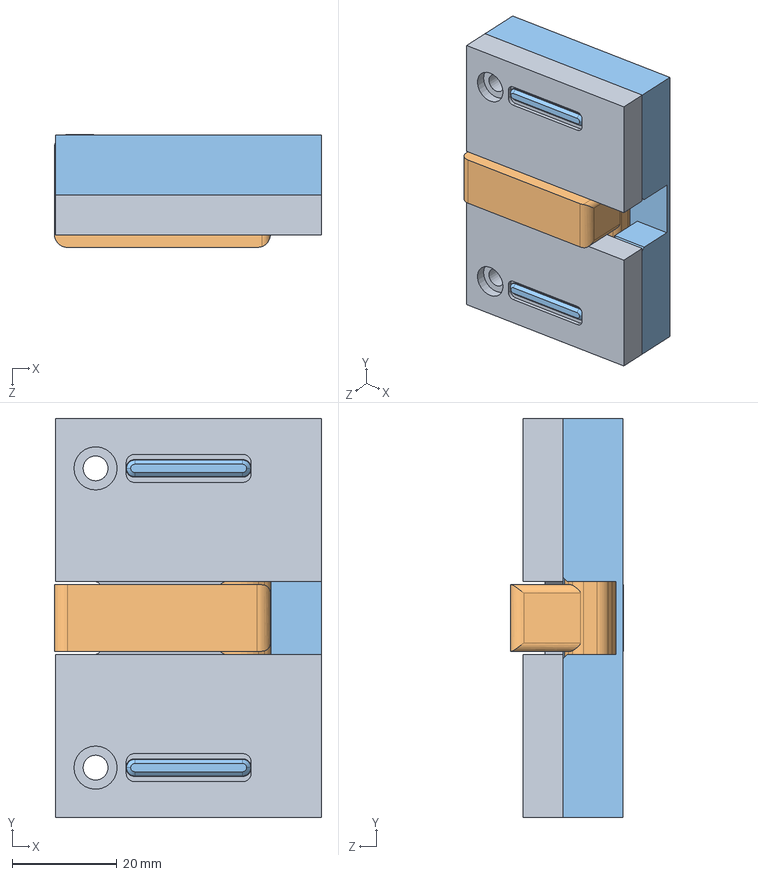
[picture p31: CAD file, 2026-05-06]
CAD:CAM Files/AssemblyA2.SLDASM
51.1 x 76.2 x 21.6 mm
Base1
Hook1
Lid 1

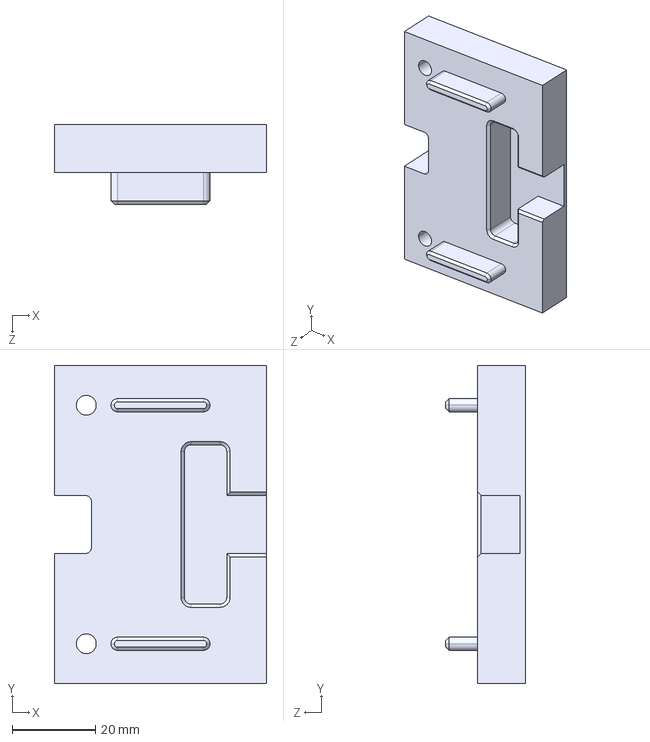
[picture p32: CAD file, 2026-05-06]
CAD:CAM Files/AssemblyA Step/Base1.STEP
50.8 x 76.2 x 19.0 mm

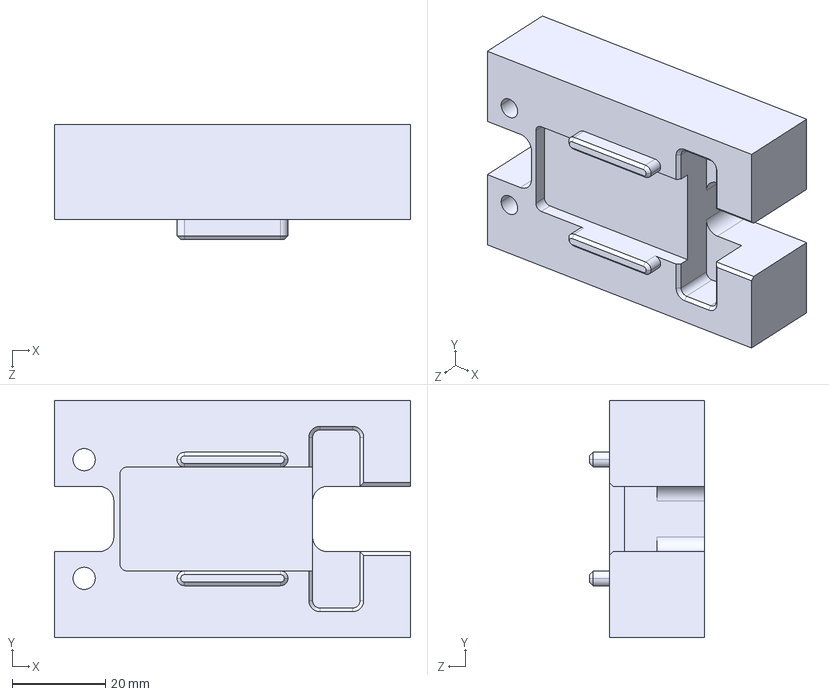
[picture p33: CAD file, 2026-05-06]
CAD:CAM Files/AssemblyB step/Base1V.STEP
76.2 x 50.8 x 24.6 mm

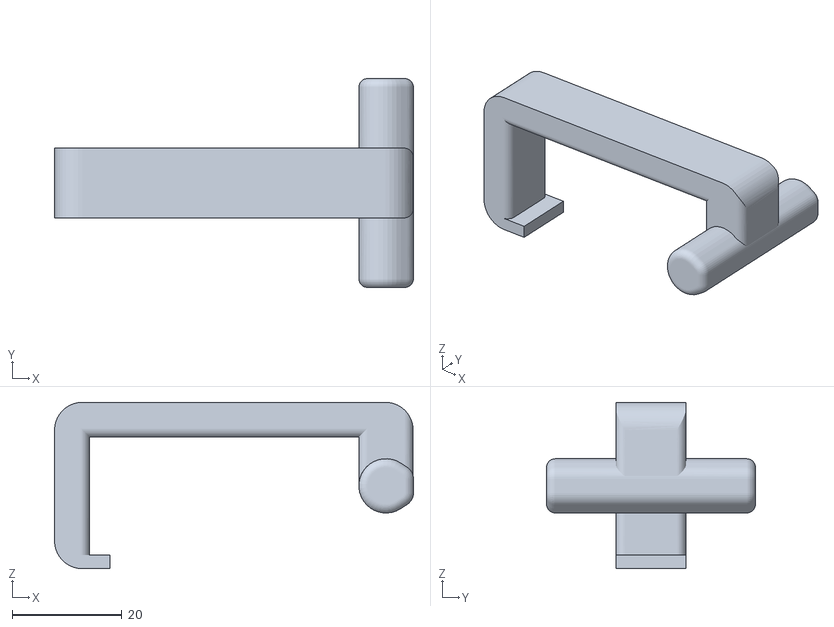
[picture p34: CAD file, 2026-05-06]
CAD:CAM Files/Hook 3d Print/Hook1V.STL
65.5 x 38.1 x 30.4

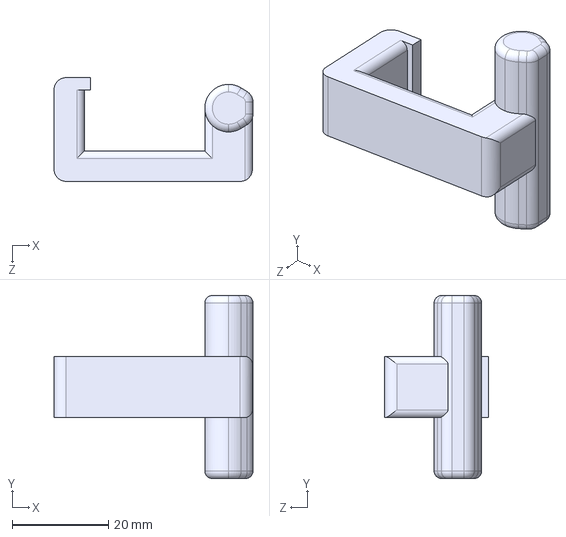
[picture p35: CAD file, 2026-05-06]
CAD:CAM Files/AssemblyA Step/Hook1.STEP
41.4 x 38.1 x 21.6 mm

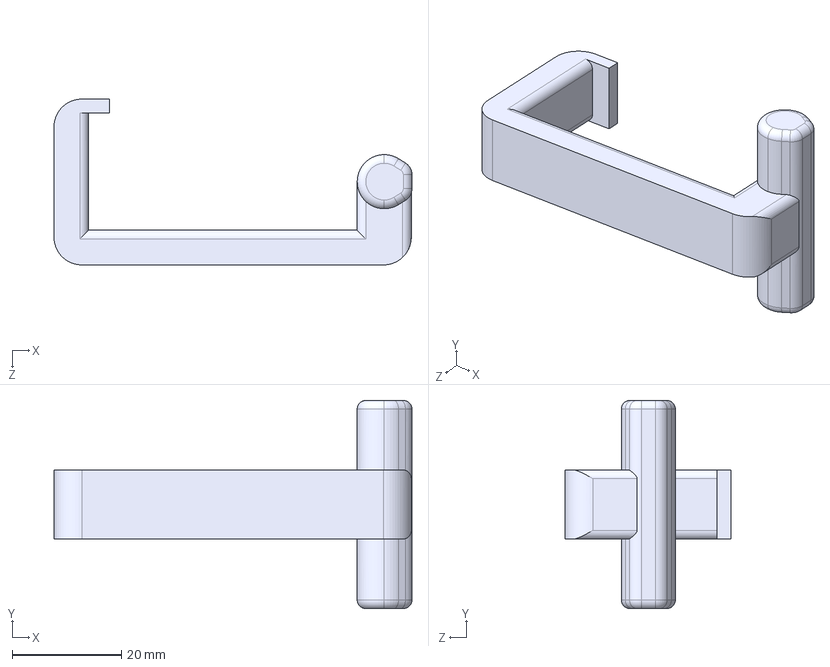
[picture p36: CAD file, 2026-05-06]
CAD:CAM Files/AssemblyB step/Hook1V.STEP
65.5 x 38.1 x 30.4 mm

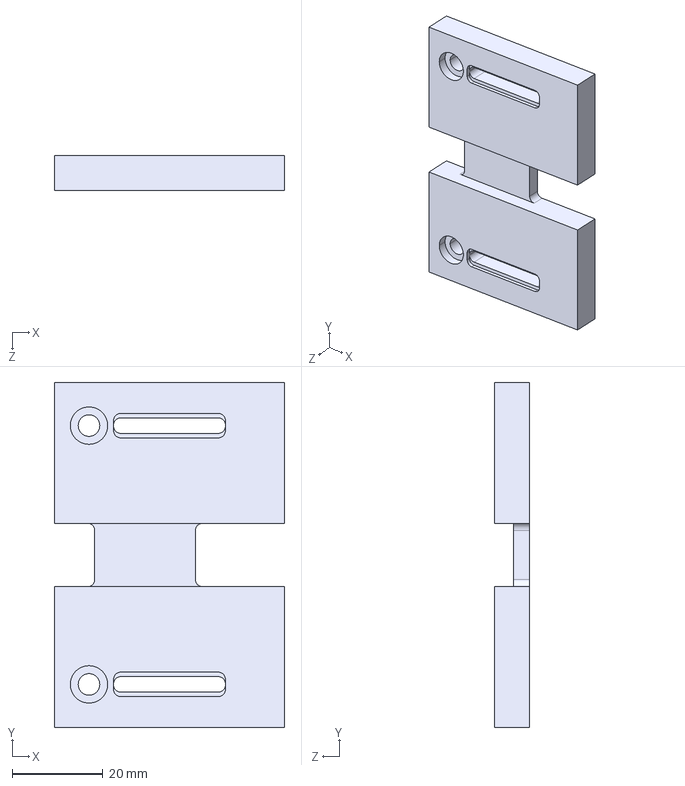
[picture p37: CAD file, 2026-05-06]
CAD:CAM Files/AssemblyA Step/Lid 1.STEP
50.8 x 76.2 x 7.62 mm

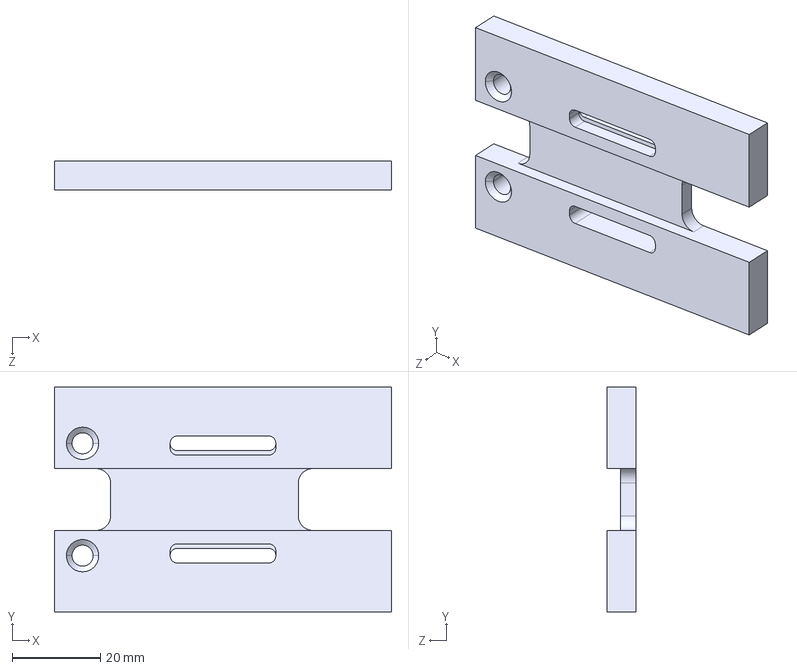
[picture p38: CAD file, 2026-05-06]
CAD:CAM Files/AssemblyB step/Lid1V.STEP
76.2 x 50.8 x 6.48 mm

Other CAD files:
CAD:CAM Files/Base1V.SLDPRT
CAD:CAM Files/Hook 3d Print/Hook1.STL
CAD:CAM Files/Hook1.SLDPRT
CAD:CAM Files/Hook1V.SLDPRT
CAD:CAM Files/Base1.SLDPRT
CAD:CAM Files/Lid1V.SLDPRT
CAD:CAM Files/Lid 1.SLDPRT
CAD:CAM Files/AssemblyA Step/Lid1.STEP

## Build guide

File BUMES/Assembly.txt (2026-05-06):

resourceSeize('Rosie')
urDashboard('Rosie','THU_530PM/Final/Short_LidToCamera.urp')
urDashboard('Rosie', 'THU_530PM/Final/Assembly_Vision.urp')

urDashboard('Rosie', 'THU_530PM/Final/Tall_LidToCamera.urp')
urDashboard('Rosie', 'THU_530PM/Final/Assembly_Vision.urp')
resourceRelease('Rosie')

//urDashboard('Rosie', 'THU_530PM/Final/Tall_LidToCamera.urp')
//urDashboard('Rosie', 'THU_530PM/Final/Assembly_Vision.urp')

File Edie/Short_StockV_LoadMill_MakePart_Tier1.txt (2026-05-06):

 Program
   BeforeStart
     Script: R2CScript.script
   Robot Program
     Run CNC Program
     Wait for CNC Program
     Set DO[1]=Off
     MoveJ
       pHome
     Call _adminLinearIndex4
     MoveJ
       Crouch
       Pivot
       aboveVise
     MoveL
       atVise
       Set DO[0]=Off
       Wait: 1.0
       aboveVise
       Set DO[0]=On
       Wait: 1.0
       besideVise
     MoveL
       pushBlock
       Set DO[1]=On
       Wait: 1.0
       besideVise
     MoveJ
       aboveVise
     MoveJ
       Pivot
       Crouch
       pHome
       Set DO[0]=Off
     Run CNC Program
   _adminLinearIndex4
     Move_linear_slide_Index4
       var_1≔ False 
       Loop var_1≟ False 
         var_1≔socket_open("10.241.34.52",4001)
       var_3≔1
       Send≔"s r0x24 21"
       socket_send_string(Send)
       socket_send_byte(13)
       Send_Reply≔socket_read_string()
       Send≔"s r0xca 169167"
       socket_send_string(Send)
       socket_send_byte(13)
       Send_Reply≔socket_read_string()
       Send≔"t 1"
       socket_send_string(Send)
       socket_send_byte(13)
       Send_Reply≔socket_read_string()
       Loop var_3≠0
         Send≔"g r0xA0"
         socket_send_string(Send)
         socket_send_byte(13)
         var_3≔socket_get_var("v")
         Wait: 0.1
       socket_close()
       sync()

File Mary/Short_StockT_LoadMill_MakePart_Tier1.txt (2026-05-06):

 Program
   BeforeStart
     Script: R2CScript.script
   Robot Program
     Run CNC Program
     Wait for CNC Program
     Set DO[1]=Off
     MoveJ
       pHome
     Call _adminLinearIndex5
     Wait: 1.0
     MoveJ
       outsideMill
       pivot
       aboveVise
     MoveL
       atVise
       Set DO[0]=Off
       Wait: 1.0
     MoveL
       aboveVise
       Set DO[0]=On
       Wait: 1.0
     MoveJ
       besideVise
     MoveL
       Wait: 1.0
       push
       Wait: 0.5
       Set DO[1]=On
       Wait: 1.0
     MoveJ
       besideVise
       pivot
       outsideMill
       pHome
     Set DO[0]=Off
     Run CNC Program
   _adminLinearIndex5
     Move_linear_slide_Index5
       var_1≔ False 
       Loop var_1≟ False 
         var_1≔socket_open("10.241.34.48",4001)
       var_3≔1
       Send≔"s r0x24 21"
       socket_send_string(Send)
       socket_send_byte(13)
       Send_Reply≔socket_read_string()
       Send≔"s r0xca 240000"
       socket_send_string(Send)
       socket_send_byte(13)
       Send_Reply≔socket_read_string()
       Send≔"t 1"
       socket_send_string(Send)
       socket_send_byte(13)
       Send_Reply≔socket_read_string()
       Loop var_3≠0
         Send≔"g r0xA0"
         socket_send_string(Send)
         socket_send_byte(13)
         var_3≔socket_get_var("v")
         Wait: 0.1
       socket_close()
       sync()

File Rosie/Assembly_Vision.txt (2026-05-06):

 Program
   BeforeStart
     visionResult≔0
   Robot Program
     'Script: vision_pc_modbus.script'
     Set DO[0]=Off
     Set DO[1]=Off
     If vision_result == 1
       MoveJ
         pHome
         Call _adminLinearIndex3
         aboveInvB
       MoveL
         atInvB
         Set DO[0]=On
         Wait: 1.0
         aboveInvB
       MoveJ
         aboveVise
       MoveL
         atVise
         Set DO[0]=Off
         Wait: 1.0
         aboveVise
         Set DO[1]=On
       MoveJ
         pHome
         Call _adminLinearIndex4
         aboveHookA
       Call hookA_manager
       Call _adminLinearIndex3
       MoveJ
         aboveHookSlotA
       MoveL
         atHookSlotA
         Set DO[0]=Off
         Wait: 1.0
         aboveHookSlotA
       MoveJ
         aboveInvA
       MoveL
         atInvA
         Set DO[0]=On
         Wait: 1.0
         aboveInvA
       MoveJ
         lidAPosAbove
       MoveL
         lidAPos1
         lidAPos2
         Set DO[0]=Off
         aboveVise
         Set DO[0]=On
       MoveL
         AboveAsm1
         AtAsm1
         AboveAsm1
         AboveAsm2
         AtAsm2
         AboveAsm2
         AboveCloseHookA
         AtCloseHookA
         CloseHookA_1
         CloseHookA_2
         PressHookA
         AbovePickA
         Set DO[0]=Off
         AtPickA
         Set DO[1]=Off
         Wait: 0.5
         Set DO[0]=On
         Wait: 1.0
         AbovePickA
       MoveJ
         FinalAboveDropA
         FinalAtDropA
         Set DO[0]=Off
         Wait: 1.0
         FinalAboveDropA
       MoveJ
         pHome
     ElseIf vision_result == 2
       MoveJ
         pHome
         Call _adminLinearIndex3
         aboveInvD
       MoveL
         atInvD
         Set DO[0]=On
         Wait: 1.0
         aboveInvD
       MoveJ
         AboveVise_B
       MoveL
         AtVise_B
         Set DO[0]=Off
         Wait: 1.0
         AboveVise_B
         Set DO[1]=On
       MoveJ
         pHome
         Call _adminLinearIndex4
         AboveHookB
       HookBManager
         above_HookB≔p[-0.39636, -0.32475, 0.15692, 2.226, -2.216, 0.000]
         offset_x≔hook_indexB * 0.047
         above_pose_B≔pose_add(above_HookB, p[0.0, -offset_x, 0.0, 0.0, 0.0, 0.0])
         at_pose_B≔pose_add(above_pose_B, p[0.0, 0.0, -0.10503, 0.0, 0.0, 0.0])
         movel (get_inverse_kin(above_pose_B))
         movel (get_inverse_kin(at_pose_B))
         Set DO[0]=On
         Wait: 1.0
         movel (get_inverse_kin(above_pose_B), a = 0.5, v = 0.1)
         movej (get_inverse_kin(above_HookB))
         hook_indexB≔hook_indexB + 1
         If hook_index ≥ num_hooks
           hook_indexB≔0
           Popup: All Hook_B's were used! Reload Fixture
       Call _adminLinearIndex3
       MoveJ
         AboveHookSlotB
       MoveL
         AtHookSlotB
         Set DO[0]=Off
         Wait: 1.0
         AboveHookSlotB
       MoveJ
         aboveInvC
       MoveL
         atInvC
         Set DO[0]=On
         Wait: 1.0
         aboveInvC
       MoveJ
         lidBPosAbove
       MoveL
         LidBPos1
         LidBPos2
         Set DO[0]=Off
         Wait: 1.0
         AboveVise_B
         Set DO[0]=On
       MoveL
         AboveAsmB1
         AtAsmB1
         AboveAsmB1
         AboveAsmB2
         AtAsmB2
         AboveAsmB2
         ToCloseHook
         AboveHookClose
         AtHookClose
         HookClose
         CloseHookPos1
         CloseHookPos2
       MoveL
         AboveVise
         Set DO[0]=Off
         AtPickB
         Set DO[1]=Off
         Wait: 1.0
         Set DO[0]=On
         Wait: 1.0
         AboveVise_B
       MoveJ
         FinalAboveDropB
         FinalAtDropB
         Set DO[0]=Off
         Wait: 1.0
         FinalAboveDropB
       MoveJ
         pHome
   hookA_manager
     above_HookA≔p[-0.27970, -0.32422, 0.12715, 2.226, -2.216, 0.000]
     offset_x≔hook_index * 0.047
     above_pose_A≔pose_add(above_HookA, p[0.0, -offset_x, 0.0, 0.0, 0.0, 0.0])
     at_pose_A≔pose_add(above_pose_A, p[0.0, 0.0, -0.086, 0.0, 0.0, 0.0])
     movel (get_inverse_kin(above_pose_A))
     movel (get_inverse_kin(at_pose_A))
     Set DO[0]=On
     Wait: 1.0
     movel (get_inverse_kin(above_pose_A), a = 0.5, v = 0.1)
     movej (get_inverse_kin(above_HookA))
     hook_index≔hook_index + 1
     If hook_index ≥ num_hooks
       hook_index≔0
       Popup: All Hook_A's were used! Reload Fixture
   _adminLinearIndex4
     Move_linear_slide_Index1
       var_1≔ False 
       Loop var_1≟ False 
         var_1≔socket_open("10.241.34.44",4001)
       var_3≔1
       Send≔"s r0x24 21"
       socket_send_string(Send)
       socket_send_byte(13)
       Send_Reply≔socket_read_string()
       Send≔"s r0xca 155904"
       socket_send_string(Send)
       socket_send_byte(13)
       Send_Reply≔socket_read_string()
       Send≔"t 1"
       socket_send_string(Send)
       socket_send_byte(13)
       Send_Reply≔socket_read_string()
       Loop var_3≠0
         Send≔"g r0xA0"
         socket_send_string(Send)
         socket_send_byte(13)
         var_3≔socket_get_var("v")
         Wait: 0.1
       socket_close()
       sync()
   _adminLinearIndex3
     Move_linear_slide_Index1
       var_1≔ False 
       Loop var_1≟ False 
         var_1≔socket_open("10.241.34.44",4001)
       var_3≔1
       Send≔"s r0x24 21"
       socket_send_string(Send)
       socket_send_byte(13)
       Send_Reply≔socket_read_string()
       Send≔"s r0xca 103936"
       socket_send_string(Send)
       socket_send_byte(13)
       Send_Reply≔socket_read_string()
       Send≔"t 1"
       socket_send_string(Send)
       socket_send_byte(13)
       Send_Reply≔socket_read_string()
       Loop var_3≠0
         Send≔"g r0xA0"
         socket_send_string(Send)
         socket_send_byte(13)
         var_3≔socket_get_var("v")
         Wait: 0.1
       socket_close()
       sync()
   _adminLinearIndex2
     Move_linear_slide_Index2
       var_1≔ False 
       Loop var_1≟ False 
         var_1≔socket_open("10.241.34.44",4001)
       var_3≔1
       Send≔"s r0x24 21"
       socket_send_string(Send)
       socket_send_byte(13)
       Send_Reply≔socket_read_string()
       Send≔"s r0xca 51968"
       socket_send_string(Send)
       socket_send_byte(13)
       Send_Reply≔socket_read_string()
       Send≔"t 1"
       socket_send_string(Send)
       socket_send_byte(13)
       Send_Reply≔socket_read_string()
       Loop var_3≠0
         Send≔"g r0xA0"
         socket_send_string(Send)
         socket_send_byte(13)
         var_3≔socket_get_var("v")
         Wait: 0.1
       socket_close()
       sync()
   _adminLinearIndex5
     Move_linear_slide_Index5
       var_1≔ False 
       Loop var_1≟ False 
         var_1≔socket_open("10.241.34.44",4001)
       var_3≔1
       Send≔"s r0x24 21"
       socket_send_string(Send)
       socket_send_byte(13)
       Send_Reply≔socket_read_string()
       Send≔"s r0xca 190000"
       socket_send_string(Send)
       socket_send_byte(13)
       Send_Reply≔socket_read_string()
       Send≔"t 1"
       socket_send_string(Send)
       socket_send_byte(13)
       Send_Reply≔socket_read_string()
       Loop var_3≠0
         Send≔"g r0xA0"
         socket_send_string(Send)
         socket_send_byte(13)
         var_3≔socket_get_var("v")
         Wait: 0.1
       socket_close()
       sync()

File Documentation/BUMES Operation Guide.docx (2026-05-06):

# BUMES Operation Guide & Supporting Documentation


ME500: Advanced Manufacturing

Spring 2026

Variable Product Manufacturing (Thursday PM Lab Group)

Chris Daub, Riley Hubscher, Mukhamed Kerimkul, Bramasto Prasojo, and Chaitanya Sai Nikith Rambha

Table of Contents

Overview 3

Operation Guide 3

BUMES System Flow 4

Appendix A: BUMES Script Descriptions 5

ShortLid: 5

ShortBody: 5

TallLid: 5

TallBody: 6

Appendix B: BUMES Script Plaintext 7

ShortLid 7

ShortBody 10

TallLid 13

TallBody 16

# Overview

This document serves as the operation guide and supporting documentation for the Variable Product Manufacturing system (VPM). This guide provides step-by-step operating instructions, a system flow diagram, and full plaintext listings of the four BUMES control scripts (ShortLid, ShortBody, TallLid, and TallBody) that orchestrate the manufacturing process. All files have been submitted to Blackboard in a ZIP file with this document.

# Operation Guide

To operate the variable product manufacturing system, follow the listed steps in the ADML:

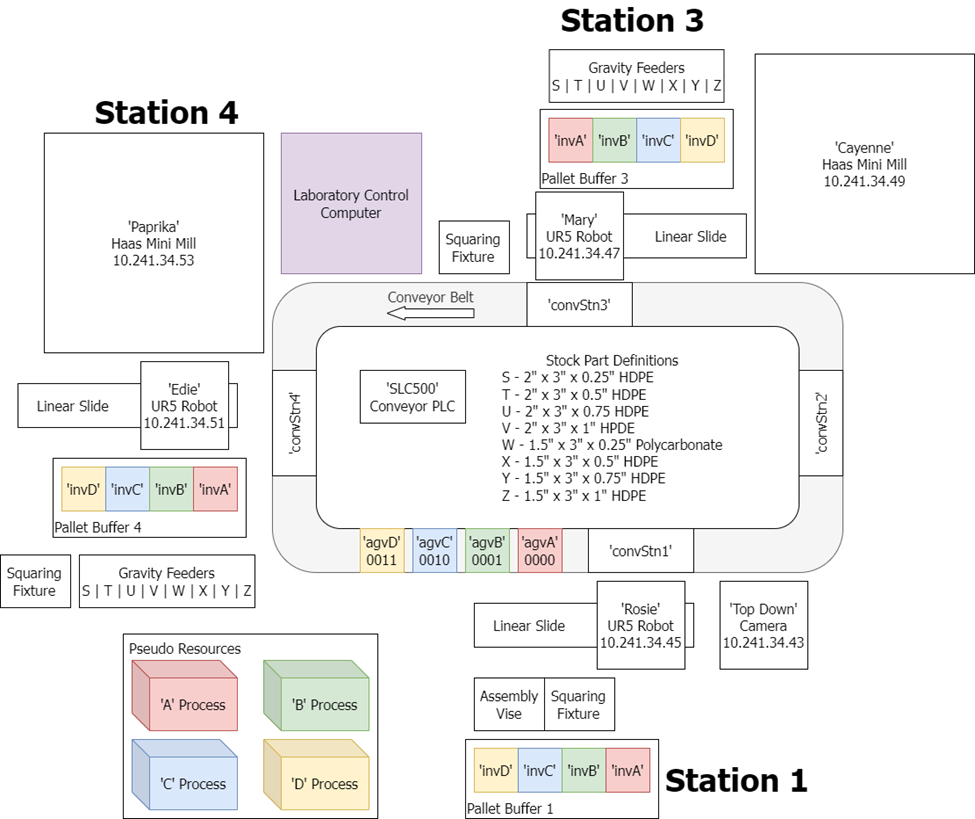
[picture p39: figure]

1. Turn on all machines in the ADML, including robots, CNC mills, conveyor belt, and master air supply to the room. Further instructions on this may be found in the respective mills for each machine. Ensure that the computer vision webcam is connected to BUMES Computer 1
2. Populate the pallet inventory bays by Rosie with pallets set for stock sizes T and V using 3D printed pegs
3. Prepare the robots for BUMES by clicking “Run Program” on the touchscreen
4. Prepare the CNC mills for BUMES by selecting program 9000 from the onboard memory. Clear any errors with the Reset key and then press “Power up/Restart”. Repeat this process if the mills fall asleep at any point
5. Fill gravity feeders with stocks T and V
6. Initialize BUMES on BUMES Computer 1
7. On the same computer, initialize the vision software by opening the provided programs listener_server.py, modbus_server.py, vision.py, vision_utils.py, and vision_extras.py. Their connections to BUMES are described in the computer vision and integration scripts manual
8. Queue and run all of the following BUMES programs:
1) ShortLid
2) ShortBody
3) TallLid
4) TallBody
9. Supervise all machines to ensure that no crashes, drops, or other failures occur. After product is delivered to the inventory bin, safely remove the product
10. Power off all machines as described in their respective manuals. Return pallets to their respective storage locations.

# BUMES System Flow

The BUMES system flow is the depicted below:

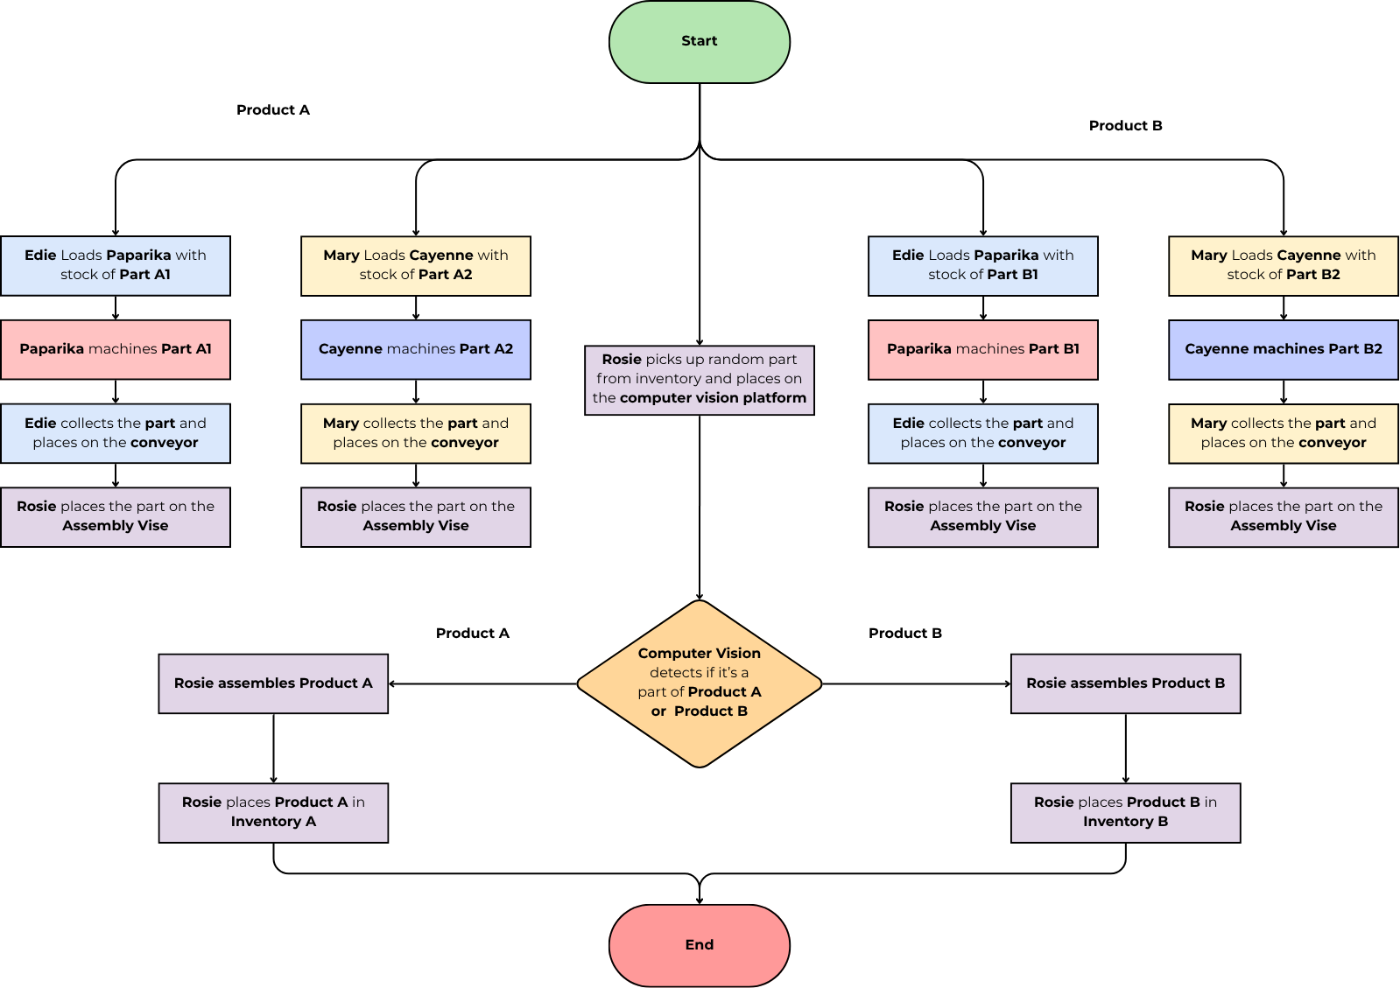
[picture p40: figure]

# Appendix A: BUMES Script Descriptions

### ShortLid:

Occurs at stations 3 (Mary, Cayenne) and 1(Rosie). Produces Lid A (short).

a. Mary: loads the stock T into the cnc machine (Cayenne)
b. Rosie: places pallet A on the conveyor at station 1.
c. Mary: places the pallet A into InvA.
d. Mary: unloads the lid ‘short’ and places it onto pallet A at InvA.
e. Mary: places the pallet A on conveyer at station 3.
f. Rosie: takes the pallet A with the lid ‘short’ on it and places it to InvA.

### ShortBody:

Occurs at stations 4 (Edie, Paprika) and 1 (Rosie). Produces Body A (short).

g. Edie: loads the stock V into the cnc machine (Paprika)
h. Rosie: places pallet B on the conveyor at station 1.
i. Edie: places the pallet B into InvB.
j. Edie: unloads the body ‘short’ and places it onto pallet B at InvB.
k. Edie: places the pallet B on conveyor at station 4.
l. Rosie: takes the pallet B with the body ‘short’ on it and places it to InvB.
m. Rosie: initializes the vision script and assembles it if the output of the computer vision is ‘short’.
n. Rosie: places the finished product to the box.

### TallLid:

Occurs at stations 3 (Mary, Cayenne) and 1(Rosie). Produces Lid B (tall).

o. Mary: loads the stock T into the cnc machine (Cayenne)
p. Rosie: places pallet C on the conveyor at station 1.
q. Mary: places the pallet C into InvC.
r. Mary: unloads the lid ‘tall’ and places it onto pallet C at InvC.
s. Mary: places the pallet C on conveyer at station 3.
t. Rosie: takes the pallet C with the lid ‘tall’ on it and places it to InvC.

### TallBody:

Occurs at stations 4 (Edie, Paprika) and 1(Rosie). Produces Body B (tall).

u. Edie: loads the stock T into the cnc machine (Paprika)
v. Rosie: places pallet D on the conveyor at station 1.
w. Edie: places the pallet D into InvD.
x. Edie: unloads the body ‘tall’ and places it onto pallet D at InvD.
y. Edie: places the pallet D on conveyor at station 4.
z. Rosie: takes the pallet D with the body ‘tall’ on it and places it to InvD.
aa. Rosie: initializes the vision script and assembles it if the output of the computer vision is ‘tall’.
bb. Rosie: places the finished product to the box.

# Appendix B: BUMES Script Plaintext

### ShortLid

//Create a lid from raw material

//Initialize System

resourceSeize('invA')

resourceSeize('A')

startupTasksComplete()

//Collect raw material and manufacture

resourceSeize('Mary')

urDashboard('Mary', 'THU_530PM/Final/gravityFeederT.urp')

urDashboard('Mary','THU_530PM/Final/Short_StockT_LoadMill_MakePart_Tier1.urp')

resourceRelease('Mary')

startupTasksComplete()

//Move Empty Pallet to Conveyor at Station 1

resourceSeize('convStn1','agvA')

resourceSeize('Rosie')

urDashboard('Rosie','THU_530PM/_adminCG-invAToPHome.urp')

urDashboard('Rosie','THU_530PM/_adminCG-PHomeToConveyor.urp')

resourceRelease('Rosie')

resourceRelease('convStn1')

//Retrieve Empty Pallet from Conveyor at Station 3

resourceSeize('convStn3','agvA')

resourceSeize('Mary')

urDashboard('Mary','THU_530PM/_adminCG-ConveyorToPHome.urp')

urDashboard('Mary', 'THU_530PM/_adminCG-PHomeToInvA.urp')

resourceRelease('Mary')

resourceRelease('convStn3')

//Move the completed lid to the inventory, then conveyor

resourceSeize('Mary')

urDashboard('Mary','THU_530PM/Final/Short_Lid_UnloadMill.urp')

urDashboard('Mary','THU_530PM/Final/Short_PHomeToInvA.urp')

resourceRelease('Mary')

resourceSeize('convStn3','agvA')

resourceSeize('Mary')

urDashboard('Mary','THU_530PM/_adminCG-InvAtoPHome.urp')

urDashboard('Mary', 'THU_530PM/_adminCG-PHomeToConveyor.urp')

resourceRelease('Mary')

resourceRelease('convStn3')

//Send finished part to station 1

resourceSeize('convStn1','agvA')

resourceSeize('Rosie')

urDashboard('Rosie','THU_530PM/_adminCG-ConveyorToPHome.urp')

urDashboard('Rosie', 'THU_530PM/_adminCG-PHomeToInvA.urp')

resourceRelease('Rosie')

resourceRelease('convStn1')

//Wait for the corresponding body, assemble, and finish

resourceRelease('A')

resourceSeize('B')

resourceSeize('Rosie')

urDashboard('Rosie','THU_530PM/_adminCG-AssembleAToB.urp')

resourceRelease('Rosie')

resourceRelease('B')

resourceSeize('A')

resourceRelease('A')

resourceRelease('invA')

### ShortBody

//Create a lid from raw material

//Initialize System

resourceSeize('invB')

resourceSeize('B')

startupTasksComplete()

//Collect raw material and manufacture

resourceSeize(Edie)

urDashboard(Edie, 'THU_530PM/Final/gravityFeederV.urp')

urDashboard(Edie,'THU_530PM/Final/Short_StockV_LoadMill_MakePart_Tier1.urp')

resourceRelease(Edie)

startupTasksComplete()

//Move Empty Pallet to Conveyor at Station 1

resourceSeize('convStn1','agvB')

resourceSeize('Rosie')

urDashboard('Rosie','THU_530PM/_adminCG-invBToPHome.urp')

urDashboard('Rosie','THU_530PM/_adminCG-PHomeToConveyor.urp')

resourceRelease('Rosie')

resourceRelease('convStn1')

//Retrieve Empty Pallet from Conveyor at Station 4

resourceSeize('convStn4','agvB')

resourceSeize(Edie)

urDashboard('Edie','THU_530PM/_adminCG-ConveyorToPHome.urp')

urDashboard('Edie', 'THU_530PM/_adminCG-PHomeToInvB.urp')

resourceRelease('Edie')

resourceRelease('convStn4')

//Move the completed lid to the inventory, then conveyor

resourceSeize('Edie')

urDashboard('Edie','THU_530PM/Final/Short_Body_UnloadMill_Tier1.urp')

urDashboard('Mary','THU_530PM/Final/Short_PHomeToInvB.urp')

resourceRelease('Edie')

resourceSeize('convStn4','agvB')

resourceSeize('Edie')

urDashboard('Edie','THU_530PM/_adminCG-InvBtoPHome.urp')

urDashboard('Edie', 'THU_530PM/_adminCG-PHomeToConveyor.urp')

resourceRelease('Edie')

resourceRelease('convStn4')

//Send finished part to station 1

resourceSeize('convStn1','agvB')

resourceSeize('Rosie')

urDashboard('Rosie','THU_530PM/_adminCG-ConveyorToPHome.urp')

urDashboard('Rosie', 'THU_530PM/_adminCG-PHomeToInvB.urp')

resourceRelease('Rosie')

resourceRelease('convStn1')

//Wait for the corresponding body, assemble, and finish

resourceRelease('B')

resourceSeize('A')

resourceSeize('Rosie')

urDashboard('Rosie','THU_530PM/Final/Short_LidToCamera.urp')

urDashboard('Rosie','THU_530PM/Final/Assembly_Vision.urp')

resourceRelease('Rosie')

resourceRelease('A')

resourceSeize('B')

resourceRelease('B')

resourceRelease('invB')

### TallLid

//Create a lid from raw material

//Initialize System

resourceSeize('invC')

resourceSeize('C')

startupTasksComplete()

//Collect raw material and manufacture

resourceSeize('Mary')

urDashboard('Mary', 'THU_530PM/Final/gravityFeederT.urp')

urDashboard('Mary','THU_530PM/Final/Tall_StockT_LoadMill_MakePart_Tier3.urp')

resourceRelease('Mary')

startupTasksComplete()

//Move Empty Pallet to Conveyor at Station 1

resourceSeize('convStn1','agvC')

resourceSeize('Rosie')

urDashboard('Rosie','THU_530PM/_adminCG-invCToPHome.urp')

urDashboard('Rosie','THU_530PM/_adminCG-PHomeToConveyor.urp')

resourceRelease('Rosie')

resourceRelease('convStn1')

//Retrieve Empty Pallet from Conveyor at Station 3

resourceSeize('convStn3','agvC')

resourceSeize('Mary')

urDashboard('Mary','THU_530PM/_adminCG-ConveyorToPHome.urp')

urDashboard('Mary', 'THU_530PM/_adminCG-PHomeToInvC.urp')

resourceRelease('Mary')

resourceRelease('convStn3')

//Move the completed lid to the inventory, then conveyor

resourceSeize('Mary')

urDashboard('Mary','THU_530PM/Final/Tall_Lid_UnloadMill.urp')

urDashboard('Mary','THU_530PM/Final/Tall_PHomeToInvC.urp')

resourceRelease('Mary')

resourceSeize('convStn3','agvC')

resourceSeize('Mary')

urDashboard('Mary','THU_530PM/_adminCG-InvCtoPHome.urp')

urDashboard('Mary', 'THU_530PM/_adminCG-PHomeToConveyor.urp')

resourceRelease('Mary')

resourceRelease('convStn3')

//Send finished part to station 1

resourceSeize('convStn1','agvC')

resourceSeize('Rosie')

urDashboard('Rosie','THU_530PM/_adminCG-ConveyorToPHome.urp')

urDashboard('Rosie', 'THU_530PM/_adminCG-PHomeToInvC.urp')

resourceRelease('Rosie')

resourceRelease('convStn1')

//Wait for the corresponding body, assemble, and finish

resourceRelease('C')

resourceSeize('D')

resourceSeize('Rosie')

resourceRelease('Rosie')

resourceRelease('D')

resourceSeize('C')

resourceRelease('C')

resourceRelease('invC')

### TallBody

//Create a lid from raw material

//Initialize System

resourceSeize('invD')

resourceSeize('D')

startupTasksComplete()

//Collect raw material and manufacture

resourceSeize('Edie')

urDashboard('Edie', 'THU_530PM/Final/gravityFeederV.urp')

urDashboard('Edie','THU_530PM/Final/Tall_StockV_LoadMill_MakePart_Tier3.urp')

resourceRelease('Edie')

startupTasksComplete()

//Move Empty Pallet to Conveyor at Station 1

resourceSeize('convStn1','agvD')

resourceSeize('Rosie')

urDashboard('Rosie','THU_530PM/_adminCG-invDToPHome.urp')

urDashboard('Rosie','THU_530PM/_adminCG-PHomeToConveyor.urp')

resourceRelease('Rosie')

resourceRelease('convStn1')

//Retrieve Empty Pallet from Conveyor at Station 4

resourceSeize('convStn4','agvD')

resourceSeize('Edie')

urDashboard('Edie','THU_530PM/_adminCG-ConveyorToPHome.urp')

urDashboard('Edie', 'THU_530PM/_adminCG-PHomeToInvD.urp')

resourceRelease('Edie')

resourceRelease('convStn4')

//Move the completed lid to the inventory, then conveyor

resourceSeize('Edie')

urDashboard('Edie','THU_530PM/Final/Tall_Lid_UnloadMill.urp')

urDashboard('Edie','THU_530PM/Final/Tall_PHomeToInvD.urp')

resourceRelease('Edie')

resourceSeize('convStn4','agvD')

resourceSeize('Edie')

urDashboard('Edie','THU_530PM/_adminCG-InvDtoPHome.urp')

urDashboard('Edie', 'THU_530PM/_adminCG-PHomeToConveyor.urp')

resourceRelease('Edie')

resourceRelease('convStn4')

//Send finished part to station 1

resourceSeize('convStn1','agvD')

resourceSeize('Rosie')

urDashboard('Rosie','THU_530PM/_adminCG-ConveyorToPHome.urp')

urDashboard('Rosie', 'THU_530PM/_adminCG-PHomeToInvD.urp')

resourceRelease('Rosie')

resourceRelease('convStn1')

//Wait for the corresponding body, assemble, and finish

resourceRelease('D')

resourceSeize('C')

resourceSeize('Rosie')

urDashboard('Rosie','THU_530PM/Final/Tall_LidToCamera.urp')

urDashboard('Rosie','THU_530PM/Final/Assembly_Vision.urp')

resourceRelease('Rosie')

resourceRelease('C')

resourceSeize('D')

resourceRelease('D')

resourceRelease('invD')

ME500: Advanced Manufacturing Daub, Hubscher, Kerimkul, Prasojo, and Rambha

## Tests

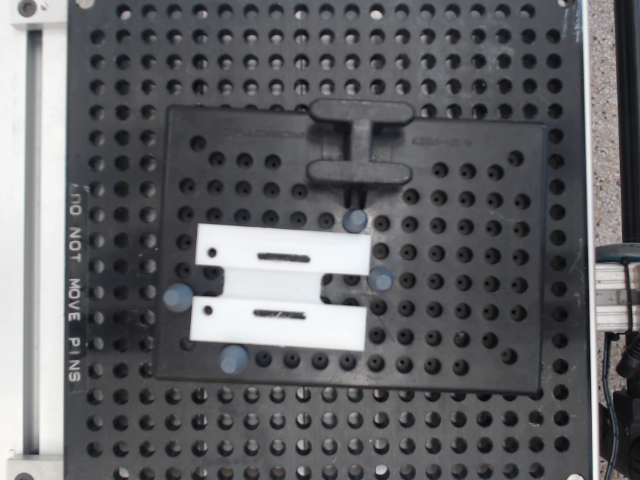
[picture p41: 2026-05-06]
Vision/BulkTest/tall1.png

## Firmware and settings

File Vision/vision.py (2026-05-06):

import math
import cv2
import modbus_server
from vision_utils import crop, RESULT_CODES, drawStuffShowStuff

# Safely Opens camera and captures camera 
def scan():
    camera = None
    image = None

    try:
        camera = cv2.VideoCapture(cv2.CAP_DSHOW)
        if not camera.isOpened():
            print(f"[scan] ERROR: Camera failed to open")
            return None

    except Exception as e:
        print(f"[scan] ERROR: Exception opening camera: {e}")
        if camera is not None:
            camera.release()
        return None

    # Attempts to capture image 3 times
    # Skipping first 30 frames
    for i in range(0,3):
        for i in range(30):
            ret, image = camera.read()
        if(ret): break
    camera.release()

    if image is None:
        print("[scan] ERROR: Failed to capture frame.")
        return None
    return image

# Sets all values less than threshold to black
# https://docs.opencv.org/4.x/d7/dd0/tutorial_js_thresholding.html
def clipBlacks(image):
    clipLevel = 200
    dst = cv2.cvtColor(image, cv2.COLOR_BGR2GRAY)
    _, dst = cv2.threshold(dst, clipLevel, 255, cv2.THRESH_TOZERO)
    return dst


# Initialize Blob (circle) Detector and returns key data (radius, location, etc)
# https://docs.opencv.org/4.x/d0/d7a/classcv_1_1SimpleBlobDetector.html
def findHoles(image):
    params = cv2.SimpleBlobDetector_Params()
    params.filterByArea = True
    params.minArea = 25
    params.maxArea = 1000

    params.filterByCircularity = True
    params.minCircularity = 0.5  # 1.0 = perfect circle, low threshold because of crop

    params.filterByConvexity = False
    params.filterByInertia = False
        
    detector = cv2.SimpleBlobDetector_create(params)
    circles = detector.detect(image)

    return circles 

# Finds largest all white area
#https://docs.opencv.org/4.x/d3/dc0/group__imgproc__shape.html#ga107a78bf7cd25dec05fb4dfc5c9e765f
def findLargestConnected(image):
    # Otsu Binarization (Split into blacks and whites)
    _, mask = cv2.threshold(image,0,255,cv2.THRESH_BINARY+cv2.THRESH_OTSU)
    numLabels, labels, stats, centroids = cv2.connectedComponentsWithStats(mask, connectivity=8)
    
    largestIndex, largestArea = 0, 0
    # skip first index, it's background
    for i in range(1, numLabels):
        x, y, w, h, area = stats[i]
        if(area > largestArea):
            largestIndex, largestArea = i, area

    return stats[largestIndex]

# Find distance between every set of pairs of circle's centerpoints
def calcHoleSpacing(holes):
    l = len(holes)
    distances = []
    for i in range(l):
        for j in range(i+1, l):
            distances.append(math.dist(holes[i].pt , holes[j].pt))
    return distances

# Determines lid type
# Algorithm takes the shortest hole distance  and splits over threshold
def lidTypeByHoles(holeSpacing, indicatorThreshold):
    lidType = RESULT_CODES[0]
    holeSpacing.sort()
    if(len(holeSpacing) == 0): 
        return lidType
    if(holeSpacing[0] < indicatorThreshold):
        lidType = RESULT_CODES[1]
    elif(holeSpacing[0] > indicatorThreshold):
        lidType = RESULT_CODES[2]

    print(holeSpacing[0])
    print(lidType)

    return lidType

# Wrapper for all image processing and indication
def lidTypeIndicator(image):

    #Crop image to just tray (this is clever :)
    clippedImage = clipBlacks(image)

    imageStats = findLargestConnected(clippedImage)
    lidCrop = crop(clippedImage, imageStats)

    # Find Features
    holes = findHoles(lidCrop)
    drawStuffShowStuff(lidCrop, holes, [])

    holeSpacing = calcHoleSpacing(holes)
    lidType = lidTypeByHoles(holeSpacing, 85)

    return lidType

# Captures image, indicates type, calls to send result
def main():
    image = scan()
    
    # Pauses algorithm for human verification
    # Uncomment DrawStuffShowStuff in lidTypeIndicator for algorithm validation
    # displayWindow(image, "Test Camera")

    lidType = lidTypeIndicator(image)
    modbus_server.set_result(lidType)

if __name__ == "__main__":
    main()

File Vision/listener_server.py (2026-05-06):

import socket
import vision

HOST = "10.241.34.37"
PORT = 30002

def start():
    with socket.socket(socket.AF_INET, socket.SOCK_STREAM) as s:
        s.bind((HOST, PORT))
        s.listen(1)
        print(f"Server started. Waiting for UR5 on {HOST}:{PORT}...")
        
        while True:
            conn, addr = s.accept()
            with conn:
                print(f"Connected by {addr}")
                data = conn.recv(1024).decode('utf-8')
                if data == "run_vision":
                    vision.main()
                conn.sendall(b"UR Command Recieved")  # Send acknowledgment back to robot

if __name__ == "__main__":
    start()

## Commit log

2026-05-06 Initial commit - Add all project files
    [AssemblyA2.SLDASM, AssemblyB2.SLDASM, Base1.SLDPRT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]
2026-05-06 Update assembly descriptions in README.md
